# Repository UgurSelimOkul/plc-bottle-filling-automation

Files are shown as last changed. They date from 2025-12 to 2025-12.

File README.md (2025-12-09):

# 🏭 Industrial Bottle Filling & Packaging Automation

**An end-to-end industrial automation project designed for a 6-bottle filling, capping, and packaging line.**

This project encompasses the complete engineering lifecycle: from mechanical 3D design and cost analysis to system architecture using **Siemens S7-1200 PLC** and **TIA Portal**.

---

## 📖 Table of Contents
1. [Project Overview](#-project-overview)
2. [System Architecture](#-system-architecture)
3. [Hardware & Components](#-hardware--components)
4. [Process Flow](#-process-flow)
5. [3D Design & Mechanical Layout](#-3d-design--mechanical-layout)
6. [Technical Documentation](#-technical-documentation)
7. [Budget Analysis](#-budget-analysis)

---

## 🎯 Project Overview

The goal of this project is to automate the liquid filling and packaging process to increase efficiency, hygiene, and traceability in industrial sectors such as food, beverage, and pharmaceuticals.

**Key Features:**
* **Dual Conveyor System:** Continuous flow management.
* **Station-Based Processing:** Filling, Capping, and Wrapping stations.
* **Smart Sensing:** IR/Optical sensors for precise positioning and counting.
* **Human-Machine Collaboration:** Semi-automatic design allowing operator intervention for quality control.

---

## ⚙️ System Architecture

The system operates on a cyclic logic controlled by a **Siemens S7-1214C PLC**.

1.  **Input Stage:** Empty bottles are fed into Conveyor 1 and counted (Batch size: 6).
2.  **Filling Station:** Bottles are clamped, and the filling robot dispenses liquid (Time-controlled).
3.  **Capping Station:** Caps are placed and tightened using a rotary actuator.
4.  **Transfer:** Operators inspect and move bottles to Conveyor 2.
5.  **Wrapping Station:** Bottles are detected, wrapped with stretch film, and counted as a finished package.

---

## 🛠 Hardware & Components

| Component | Quantity | Function |
| :--- | :--- | :--- |
| **PLC** | 1 | Siemens S7-1214C DC/DC/DC |
| **Expansion Module** | 2 | SM1222 – 16 DO Module |
| **HMI** | 1 | Siemens HMI Panel |
| **Servo Motors** | 18 | Siemens V90 (Conveyors & Robotic Arms) |
| **Sensors** | 4 | Sick GRL18S (Reflective Optical Sensor) |
| **Contactors** | 18 | Siemens 3TF40-10 |

---

## 🔄 Process Flow

The automation logic is time-window based, ensuring synchronized operations without complex interlocks.

* **T = 0-2s:** Gripper arms lock the bottles.
* **T = 2-4s:** Robot arm descends.
* **T = 4-8s:** Process execution (Filling / Capping / Wrapping).
* **T = 8-10s:** Robot arm ascends.
* **T = 10-12s:** Grippers release, conveyor moves.

---

## 🎨 3D Design & Mechanical Layout

The physical layout was modeled to ensure ergonomic operation and spatial efficiency.

### System Overview (Isometric View)
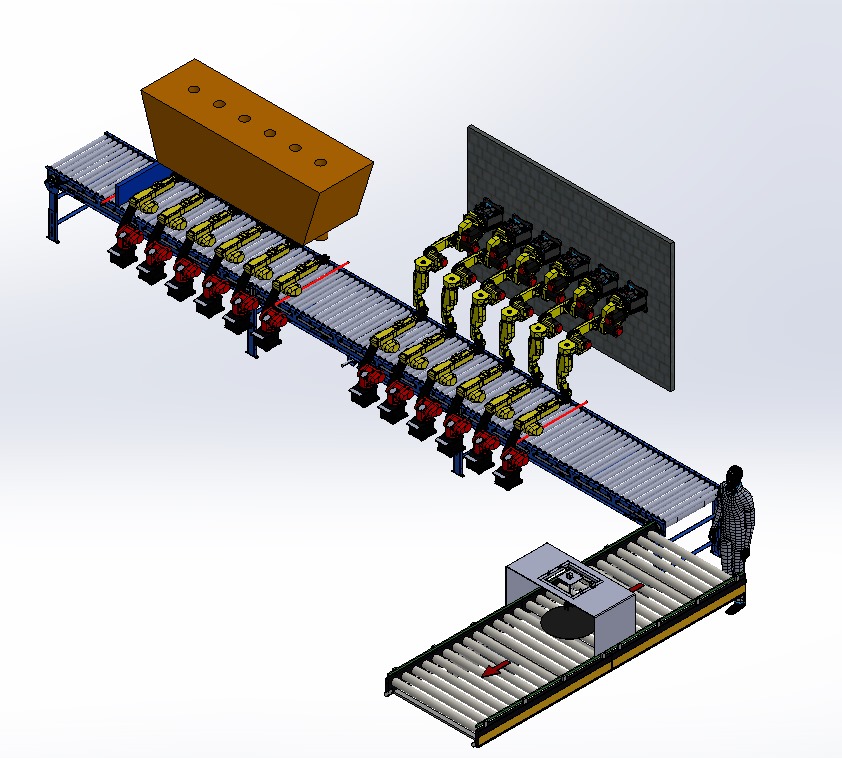
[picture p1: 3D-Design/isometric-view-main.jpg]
Isometric Main


### Front View
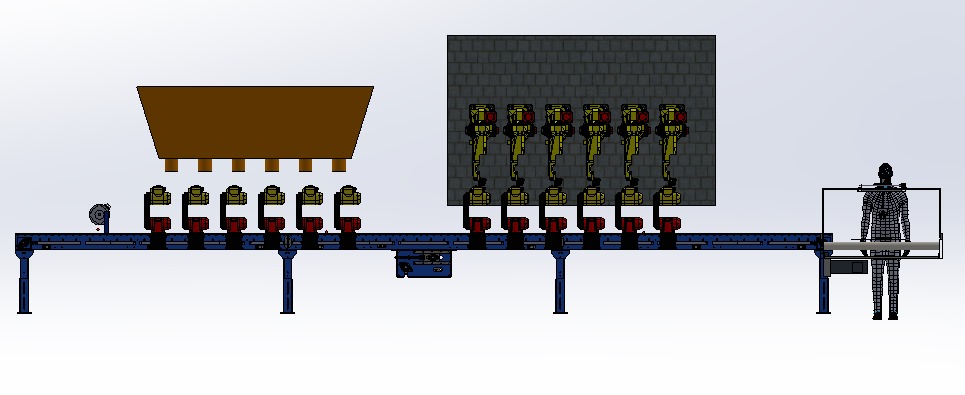
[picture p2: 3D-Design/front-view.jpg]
Front View


### Top View (Layout)
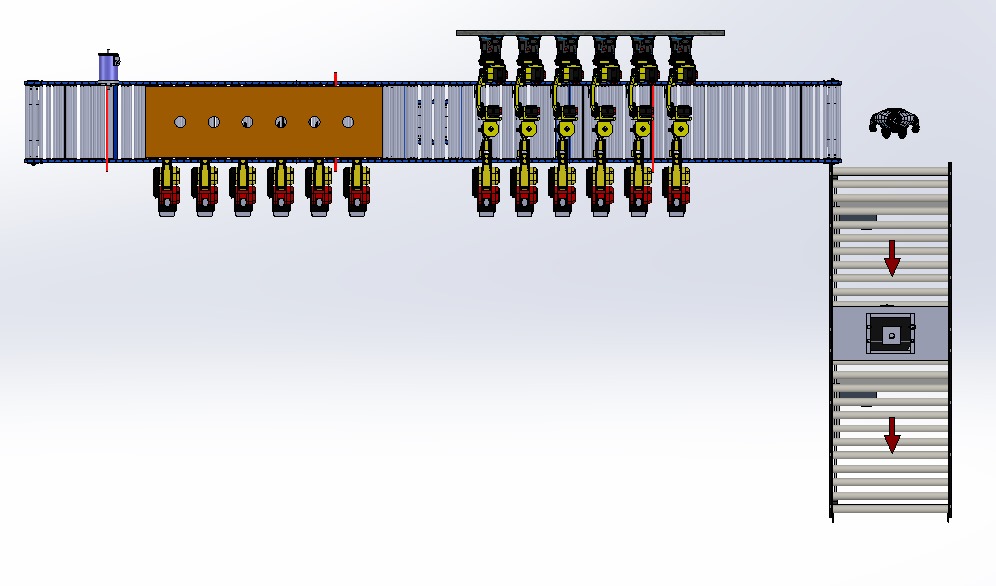
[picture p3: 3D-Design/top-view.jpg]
Top View


### Additional Angles
| Angle 1 | Angle 2 |
| :---: | :---: |
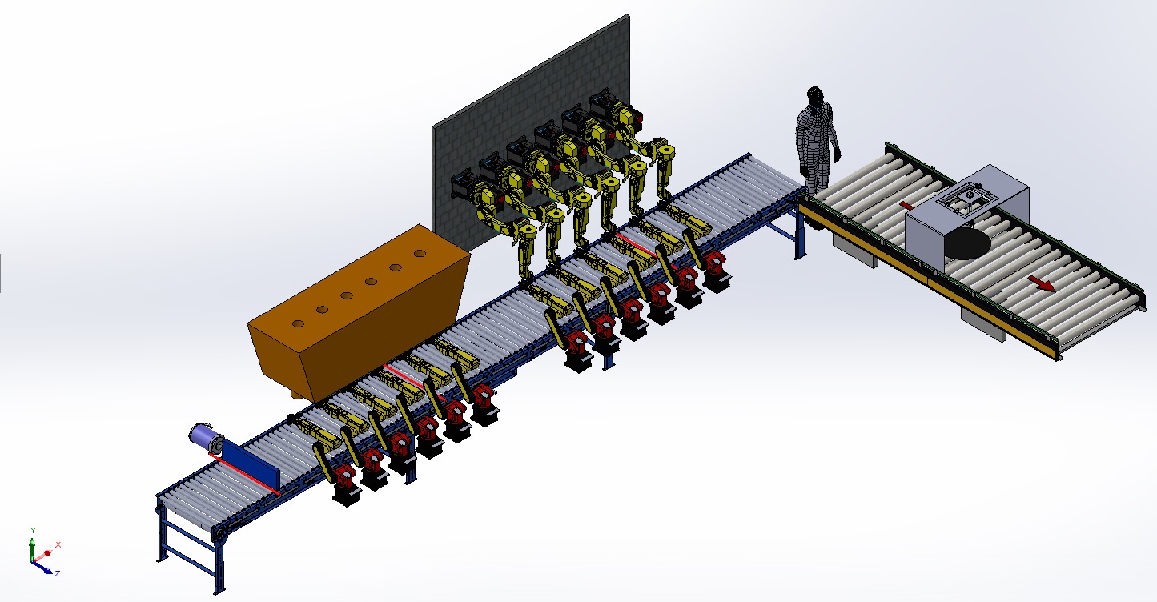
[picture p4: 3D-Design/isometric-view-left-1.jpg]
Left 1
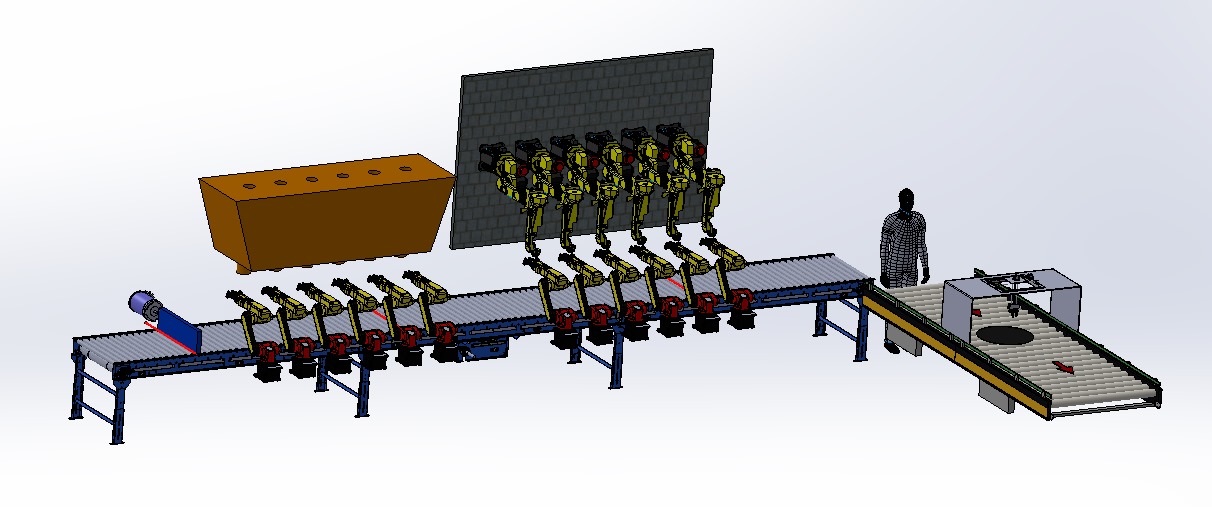
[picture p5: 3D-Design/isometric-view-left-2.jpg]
Left 2
|  |  |

---

## 📄 Technical Documentation

Detailed wiring diagrams, power circuit schematics, and PLC ladder logic diagrams are available in the full project report attached to this repository.

**The full report includes:**
* Detailed PLC Logic & Algorithms (LAD)
* Electrical Power Circuit Diagrams
* I/O Wiring Schematics

📥 **[Download Full Project Report (PDF)](Project-Report.pdf)**

---

## 💰 Budget Analysis

A comprehensive cost analysis was conducted for industrial feasibility.

| Item | Total Cost (Est.) |
| :--- | :--- |
| **PLC & Modules** | 33,600 TL |
| **HMI Panel** | 83,000 TL |
| **Servo Motors (x18)** | 248,400 TL |
| **Total System Cost** | **~415,638 TL** |

---

### 👨‍💻 Author
**Uğur Selim Okul**
*Electrical & Electronics Engineering Student*
* [GitHub Profile](https://github.com/UgurSelimOkul)

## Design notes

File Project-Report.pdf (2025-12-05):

# ENDÜSTRİYEL OTOMASYON

# 6’lı Şişe Dolum ve Paketleme

# UĞUR SELİM OKUL

## 21 MAYIS 2025

### SELÇUK ÜNİVERSİTESİ ELEKTRİK ELEKTRONİK MÜHENDİSLİĞİ

## İçindekiler

## 1. GİRİŞ

Günümüzde sanayi üretim süreçlerinin otomatikleştirilmesi, verimlilik, kalite ve hız açısından büyük önem taşımaktadır. Özellikle sıvı ürünlerin ambalajlanmasında kullanılan dolum ve paketleme otomasyon sistemleri, gıda, kimya ve ilaç sanayi gibi birçok alanda yaygın biçimde kullanılmaktadır. Bu sistemler, insan gücüne olan bağımlılığı azaltmakta; üretim hızını artırmakta ve standartlara uygun, tekrarlanabilir işlemler gerçekleştirmektedir.

Bu rapor kapsamında, iki konveyörlü, sensör kontrollü ve kısmen insan destekli bir şişe dolum ve paketleme otomasyon sistemi detaylı bir şekilde incelenmiştir. Tasarlanan sistem; şişelerin belirli sayılarda hatta alınması, dolum yapılması, kapak takılması, streçleme uygulanması ve üretim adetlerinin sayılarak gün sonunda raporlanması işlevlerini otomatik olarak yerine getirmektedir.

Çalışmada, sistemin genel yapısı, kullanılan donanım bileşenleri, işleyiş algoritması, sensör-aktüatör etkileşimi ve zamanlama mekanizmaları teknik detaylarıyla ele alınmıştır. Ayrıca sistemin gerçek dünya kullanım senaryoları ve sanayi uygulamaları da değerlendirilerek, projenin endüstriyel karşılığı vurgulanmıştır.

## 2. UYGULAMA ALANLARI VE ENDÜSTRİYEL ÖNEMİ

Şişe dolum ve paketleme sistemleri, endüstriyel otomasyonun en yaygın kullanıldığı alanlardan biridir. Yüksek hacimli, hızlı ve hijyenik üretim gereksinimi olan sektörlerde, bu tür sistemler kritik rol oynamaktadır. Otomatik dolum ve paketleme hatları aşağıdaki alanlarda yaygın biçimde kullanılmaktadır:

- Gıda Sektörü: Su, süt, meyve suyu, ayran gibi sıvı ürünlerin dolumu ve ambalajlanmasında.
- İçecek Endüstrisi: Gazlı içecekler, enerji içecekleri ve aromalı içeceklerin şişelenmesinde.
- Kimya Sanayi: Temizlik ürünleri, sıvı sabunlar, dezenfektanlar ve solvent bazlı sıvıların dolumunda.
- İlaç ve Medikal Sektör: Şurup, serum ve sıvı ilaçların dolumunda, hijyenik ve kontrollü ortam gereksinimiyle.
- Kozmetik Endüstrisi: Kolonya, parfüm, yüz tonikleri gibi sıvı kozmetik ürünlerin ambalajlanmasında.

Bu sistemlerin tercih edilmesindeki temel nedenler şunlardır:

- Üretim Hızı: İnsan gücüne göre çok daha hızlı, kesintisiz ve standardize edilmiş üretim.
- Hijyen: Özellikle gıda ve ilaç sektörlerinde, temasın minimuma indirilmesi.
- İzlenebilirlik: Sayıcı sistemler ve sensörler ile üretimin anlık takibi ve raporlanması.
- İş Gücü Tasarrufu: Sürecin büyük kısmı otomatik olduğu için daha az personelle daha fazla üretim yapılabilmesi.
- Hata Oranı Azaltımı: Zamanlamaya dayalı sistemler sayesinde kapak takma, dolum seviyesi gibi adımlarda hata olasılığı düşürülür.

Sonuç olarak, geliştirilen bu sistem yalnızca teorik bir proje değil, gerçek endüstriyel ihtiyaçlara yanıt veren, ölçeklenebilir bir otomasyon çözümünün temelini oluşturmaktadır.

## 3. SİSTEMİN GENEL TANIMI

Tasarımı gerçekleştirilen şişe dolum ve paketleme otomasyon sistemi, üretim hattında sıvı ürünlerin kapalı ve taşıma hazır hâle getirilmesini sağlayan çok aşamalı bir yapıya sahiptir. Sistem, iki ana konveyör hattı ve bu hatlar üzerinde yer alan sensörler, robot kollar, aktüatörler ve zaman kontrollü motorlar ile entegre bir şekilde çalışmaktadır. Temel hedef; sürekli bir şişe akışı sağlayarak, üretimin kesintisiz ve kontrollü biçimde sürdürülmesidir.

İşleyiş mantığı şu şekilde özetlenebilir:

1. Konveyör 1 üzerinde dış ortamdan gelen boş şişeler, bir sensör yardımıyla sayılarak 6'lı gruplar hâlinde hatta alınır. Sayı 6 olduğunda sistem geçici olarak şişe girişini durdurur.
2. Şişeler sırayla dolum istasyonuna ulaşır. Bu istasyonda tutucu kollar, şişeleri sabitler; dolum robotu aşağı inerek belirlenen süre boyunca sıvı dolumunu gerçekleştirir. İşlem tamamlandığında sistem kendini sıfırlar ve şişeler ilerlemeye devam eder.
3. Bir sonraki adımda şişeler kapak takma istasyonuna ulaşır. Burada yine tutucu kollar şişeleri tutar, ardından kapak takma robotu ve döndürücü mekanizma kapakları sıkıca yerleştirir.
4. Şişeler bu işlemlerden sonra bir insan operatör tarafından konveyör 1 sonundan alınır ve düzgün biçimde Konveyör 2 üzerine yerleştirilir.
5. Konveyör 2 operatör tarafından çalıştırıldığında, şişeler streçleme istasyonuna ulaşır. Burada şişeler sensör ile algılanır ve konveyör 2 durdurulur. Streçleme motoru belirli bir süre çalışarak şişeleri sarar ve işlemi tamamlar.
6. Streçlenmiş şişeler ilerlerken çıkıştaki sayaç ve sensör sistemiyle toplam üretim miktarı kaydedilir.

Bu yapı ile sistem hem otomatik kontrol hem de yarı-insan destekli müdahale adımlarını birleştirerek, esnek ve pratik bir üretim süreci sunar. Tüm kritik hareketler; süre, sensör geri bildirimi veya kullanıcı girişi (örneğin start butonu) ile tetiklenmektedir.

Döngüsel İşleyiş:
Sistem, kapak takma işlemi tamamlandıktan sonra otomatik olarak yeni 6'lı şişe grubunu hatta almak üzere tekrar başa döner. Bu sayede üretim hattı, manuel durdurma harici sürekli akış hâlinde çalışabilir.

Genel Yapı Özellikleri:

- Çok istasyonlu otomasyon
- Sensör-tabanlı geri besleme kontrolü
- Zamanlayıcı destekli aktüatör kontrolü
- İnsan destekli geçiş ve kalite kontrol
- Üretim takibi için entegre sayaç sistemi

## 4. DONANIM BİLEŞENLERİ VE GÖREVLERİ

Tasarlanan sistemde, şişelerin işlenmesi sırasında farklı aşamalarda çeşitli sensörler, motorlar, tutucu kollar ve kontrol elemanları görev yapmaktadır. Bu bileşenler, süreç boyunca ürün akışını yönlendirmek, işlem yapmak ve süreci kontrol etmek amacıyla kullanılır. Aşağıda sistemde yer alan donanım bileşenleri ve işlevleri detaylı olarak açıklanmıştır:

Sensörler

Sensör Adı | Türü | Konumu | Görevi
Sensör 1 | IR/optik | Konveyör 1 girişinde bulunur. | Şişe hattına giren her şişeyi algılar, giriş sayacını bir artırır. Sayaç 6’ya ulaştığında giriş motorunun durmasını sağlar.
Sensör 2 | IR/optik | Dolum istasyonunda bulunur. | Şişelerin dolum pozisyonuna geldiğini algılar; Tutucu Kol 1-6’nın ileri hareketini ve dolum robotunun aşağı inmesini tetikler.
Sensör 3 | IR/optik | Kapak takma bölgesinde bulunur. | Şişelerin kapak yerleştirme pozisyonuna ulaştığını algılar; Tutucu Kol 7-12’nin ileri hareketini ve kapak robotunun çalışmasını başlatır.
Sensör 4 | IR/optik | Streçleme bölgesinde bulunur. | Şişelerin streçleme pozisyonuna ulaştığını algılar; konveyör 2’yi durdurur ve streçleme motorunun çalışmasını başlatır. Streçleme işlemi tamamlandığında, bir paket tamamlandığı için paket sayacını bir artırır.

Sayıcılar

Sayıcı | Bağlı Olduğu Sensör | Görevi
Şişe Giriş Sayacı | Sensör 1 | Konveyöre giren her şişeyi sayar. 6’ya ulaştığında şişe alma işlemini durdurur.
Paket Sayacı | Sensör 4 | Streçleme işlemi tamamlandığında bir paketi sayar ve üretim adedini artırır.

Motorlar ve Aktüatörler

Bileşen | Görevi | Hareket Yönü | Tetikleyici
Giriş Motoru | Konveyör 1’e şişe alır | Tek yönlü (ileri) | Ana Start aktifken çalışır. Sensör 1 sayacı 6’ya ulaştığında durur.
Konveyör 1 Motoru | Şişeleri istasyonlara taşır | Tek yönlü (ileri) | Ana Start ile sürekli çalışır.
Tutucu Kol 1 Tutucu Kol 2 Tutucu Kol 3 Tutucu Kol 4 Tutucu Kol 5 Tutucu Kol 6 | Dolum istasyonunda şişeleri sabitler | İleri / Geri | Sensör 2 ile ileri hareket eder, dolum sonrası geri döner

Dolum Robotu | Dolum iğnesini şişe içine indirip çıkarır | Aşağı / Yukarı | Tutucu Kol 1 ileri pozisyondaysa → robot aşağı iner, vana açma için konum alır.
Dolum Vanası | Sıvı akışını kontrol eder | Aç / Kapa (solenoid) | Dolum robotu aşağıdayken → zamanlayıcı ile belirli süre açılır, sonra kapanır.
Tutucu Kol 7 Tutucu Kol 8 Tutucu Kol 9 Tutucu Kol 10 Tutucu Kol 11 Tutucu Kol 12 | Kapak takma istasyonunda şişeleri sabitler | İleri / Geri | Sensör 3 ile ileri gider, kapaklama sonrası geri döner.
Kapak Robotu | Kapağı şişeye indirir ve yerleştirir | Aşağı / Yukarı | Sensör 3 ile tetiklenir → aşağı iner, ardından döndürücü başlar. Döndürme bitince yukarı çıkar.
Döndürücü Motor | Kapağı döndürerek sıkar | Dönme hareketi | Kapak robotu aşağıdayken çalışır, zamanlayıcı ile belirli süre döner.
İnsan Operatör | Şişeleri Konveyör 2’ye dizmekle görevlidir | Manuel işlem | Kapaklanmış şişeleri düzenli biçimde Konveyör 2’ye yerleştirir
Konveyör 2 Motoru | Şişeleri streçleme istasyonuna taşır | Tek yön (ileri) | Sadece Konveyör 2 Start butonuna basıldığında çalışır.
Streçleme Robotu | Streçleme motorunu şişe hizasına indirip kalır. | Aşağı / Yukarı | Sensör 4 sonrası → önce aşağı iner, döndürme sonrası yukarı kalkar.
Streçleme Motoru | Streç filmle sarma işlemini yapar | Dönme hareketi | Streçleme robotu aşağıdayken çalışır, zamanlayıcı ile belirli süre döner.

Zamanlayıcılar
Tasarlanan otomasyon sisteminde, işlemlerin zaman kontrollü olarak senkronize biçimde yürütülmesi amacıyla her istasyon için tek zamanlayıcıya dayalı zaman pencereli kontrol yöntemi uygulanmıştır Sistemde, her istasyon için toplam işlem süresi sabitlenmiştir. Bu toplam süre, alt adımlara bölünerek her bir hareket veya işlem, belirlenen zaman aralıklarında başlatılır ve sonlandırılır. Böylece, her bir istasyon yalnızca bir zamanlayıcıya ihtiyaç duyarak, minimum kaynak kullanımıyla kesintisiz bir çalışma gerçekleştirebilmektedir.

İstasyon | Kontrol Edilen İşlemler | Zaman Aralıkları | Açıklama / İşlev
Dolum İstasyonu | Tutucu kol ileri Dolum robotu aşağı Vana açma Dolum robotu yukarı Tutucu kol geri | 0–2 sn 2–4 sn 4–8 sn 8–10 sn 10–12 sn | Şişe sabitlenir, dolum robotu aşağı iner, vana açılır ve 4 saniye dolum yapılır. Ardından robot yukarı çıkar ve tutucu kol geri döner.
Kapak Takma İstasyonu | Tutucu kol ileri Kapak robotu aşağı Döndürme aktif Kapak robotu yukarı Tutucu kol geri | 0–2 sn 2–4 sn 4–8 sn 8–10 sn 10–12 sn | Şişe tutulur, kapak robotu kapağı indirir, döndürme işlemi yapılır, robot yukarı kalkar ve kol geri çekilir.
Streçleme İstasyonu | Robot aşağı Motor dön Robot yukarı | 0–2 sn 2–6 sn 6–8 sn | Konveyör 2 durur, robot aşağı iner, streçleme motoru belirli süre döner, robot yukarı kalkar ve konveyör 2 tekrar çalışır.

Giriş / Çıkış Portları (I/O Analizi)
Otomasyon sisteminde kullanılan tüm sensörler, butonlar ve aktüatörler; dijital giriş ve çıkış pinleri üzerinden kontrol edilmekte ve denetlenmektedir. Endüstride yaygın olarak kullanılan PLC sistemleri referans alınarak, girişler Ix.y ve çıkışlar Qx.y formatında adreslenmiştir. Bu yapı, sistemin sahada uygulanabilirliğini kolaylaştırmakta, modülerliği ve okunabilirliği artırmaktadır.
Adresler atanırken, benzer işleve sahip bileşenler ardışık olarak gruplanmış ve sistemin genel akışına uygun şekilde sıralanmıştır. Böylece kontrol mantığı sahada daha kolay entegre edilebilir hale getirilmiştir.

Dijital Giriş Elemanları

Adres | Eleman Adı | Görevi
I0.0 | Sensör 1 | Konveyör 1 girişinde şişe algılar; giriş sayacını artırır.
I0.1 | Sensör 2 | Dolum pozisyonuna gelen şişeyi algılar; dolum sürecini başlatır.
I0.2 | Sensör 3 | Kapak takma pozisyonundaki şişeyi algılar; kapaklama işlemini tetikler.
I0.3 | Sensör 4 | Streçleme pozisyonuna gelen şişeyi algılar; işlem ve sayımı başlatır.
I0.4 | Ana Start Butonu | Tüm sistemi başlatır.
I0.5 | Ana Stop Butonu | Sistemi durdurur.
I0.6 | Konveyör 2 Start Butonu | Konveyör 2'yi manuel olarak başlatır.
I0.7 | Acil Durdurma Butonu | Sistemdeki tüm enerjiyi keser.
TOPLAM GİRİŞ SAYISI | | 8

Dijital Çıkış Elemanları

Adres | Eleman Adı | Görevi
Q0.0 | Giriş Motoru | Konveyör 1’e şişe alır.
Q0.1 | Konveyör 1 Motoru | Şişeleri dolum ve kapak istasyonlarına taşır.
Q0.2 | Tutucu Kol 1 – İleri | Dolum istasyonunda şişeyi sabitler.

Q0.3 | Tutucu Kol 1 – Geri | Sabitlenen şişeyi serbest bırakır.
Q0.4 | Tutucu Kol 2 – İleri | Dolum istasyonunda şişeyi sabitler.
Q0.5 | Tutucu Kol 2 – Geri | Sabitlenen şişeyi serbest bırakır.
Q0.6 | Tutucu Kol 3 – İleri | Dolum istasyonunda şişeyi sabitler.
Q0.7 | Tutucu Kol 3 – Geri | Sabitlenen şişeyi serbest bırakır.
Q1.0 | Tutucu Kol 4 – İleri | Dolum istasyonunda şişeyi sabitler.
Q1.1 | Tutucu Kol 4 – Geri | Sabitlenen şişeyi serbest bırakır.
Q8.0 | Tutucu Kol 5 – İleri | Dolum istasyonunda şişeyi sabitler.
Q8.1 | Tutucu Kol 5 – Geri | Sabitlenen şişeyi serbest bırakır.
Q8.2 | Tutucu Kol 6 – İleri | Dolum istasyonunda şişeyi sabitler.
Q8.3 | Tutucu Kol 6 – Geri | Sabitlenen şişeyi serbest bırakır.
Q8.4 | Dolum Robotu – Aşağı | Dolum kolu inişi
Q8.5 | Dolum Robotu – Yukarı | Dolum kolu inişi
Q8.6 | Dolum Vanası | Sıvı akışını başlatır/durdur
Q8.7 | Tutucu Kol 7 – İleri | Kapak Takma istasyonunda şişeyi sabitler.
Q9.0 | Tutucu Kol 7 – Geri | Kapak Takma istasyonunda şişeyi serbest bırakır.
Q9.1 | Tutucu Kol 8 – İleri | Kapak Takma istasyonunda şişeyi sabitler.
Q9.2 | Tutucu Kol 8 – Geri | Kapak Takma istasyonunda şişeyi serbest bırakır.
Q9.3 | Tutucu Kol 9 – İleri | Kapak Takma istasyonunda şişeyi sabitler.
Q9.4 | Tutucu Kol 9 – Geri | Kapak Takma istasyonunda şişeyi serbest bırakır.
Q9.5 | Tutucu Kol 10 – İleri | Kapak Takma istasyonunda şişeyi sabitler.
Q9.6 | Tutucu Kol 10 – Geri | Kapak Takma istasyonunda şişeyi serbest bırakır.
Q9.7 | Tutucu Kol 11 – İleri | Kapak Takma istasyonunda şişeyi sabitler.
Q12.0 | Tutucu Kol 11 – Geri | Kapak Takma istasyonunda şişeyi serbest bırakır.
Q12.1 | Tutucu Kol 12 – İleri | Kapak Takma istasyonunda şişeyi sabitler.
Q12.2 | Tutucu Kol 12 – Geri | Kapak Takma istasyonunda şişeyi serbest bırakır.
Q12.3 | Kapak Robotu – Aşağı | Kapak indirme
Q12.4 | Kapak Robotu – Yukarı | Kapak kaldırma
Q12.5 | Döndürücü Motor | Kapak döndürme
Q12.6 | Konveyör 2 Motoru | Streçleme öncesi taşıma
Q12.7 | Streçleme Robotu – Aşağı | Streç nozulu aşağı iner.
Q13.0 | Streçleme Robotu – Yukarı | Sarma işlemi tamamlandıktan sonra yukarı çıkar.
Q13.1 | Streçleme Motoru | Streç film sarımını gerçekleştirir.
TOPLAM ÇIKIŞ SAYISI: | | 36

## 5. SİSTEM İŞLEYİŞ AKIŞI

Genel Çalışma Mantığı

Tasarlanan şişe dolum ve ambalajlama otomasyon sistemi, konveyör hatları üzerinde sensörlerden alınan geri bildirimlerle çalışan motor, aktüatör ve zaman kontrollü işlemlerden oluşmaktadır. Sistemin kontrolü, Ana Start butonuna basılması ile başlar ve tüm işlemler sıralı biçimde gerçekleşir. Her istasyon belirli bir işlem süresine sahiptir ve bu süre içerisinde alt adımlar belirlenen zaman aralıklarında gerçekleştirilir.

Sistem ayrıca yarı otomatik bir yapıya sahiptir. Şişelerin Konveyör 2 üzerine dizilmesi, insan operatör tarafından gerçekleştirilmektedir.

İşleyiş Adımları

1. Ana Start butonuna basılır ve sistem devreye girer.
2. Giriş motoru (Q0.0) çalışarak Konveyör 1 üzerine şişe almaya başlar.
3. Sensör 1 (I0.0) şişeleri algılayarak giriş sayacını artırır. Sayaç değeri 6 olduğunda, giriş motoru durur.
4. Konveyör 1 motoru (Q0.1) aktif hale gelir ve şişeleri dolum istasyonuna taşır.
5. Sensör 2 (I0.1) dolum pozisyonuna gelen şişeyi algılar ve dolum istasyonu zamanlayıcısı başlar:
- 0–2 sn: Tutucu Kol 1-6 (Q0.2, Q0.4, Q0.6, Q1.0, Q8.0, Q8.2) ileri hareket eder.
- 2–4 sn: Dolum Robotu (Q8.4) aşağı iner.
- 4–8 sn: Dolum Vanası (Q8.6) açılır ve sıvı dolumu yapılır.
- 8–10 sn: Dolum Robotu (Q8.5) yukarı çıkar.
- 10–12 sn: Tutucu Kol 1-6 (Q0.3, Q0.5, Q0.7, Q1.1, Q8.1, Q8.3) geri hareket eder.
6. Şişeler kapak istasyonuna ilerler. Sensör 3 (I0.2) bu noktada devreye girer ve kapaklama süreci başlar:
- 0–2 sn: Tutucu Kol 7-12 (Q8.7, Q9.1, Q9.3, Q9.5, Q9.7, Q12.1) ileri hareket eder.
- 2–4 sn: Kapak Robotu – Aşağı (Q12.3) çalışır.
- 4–8 sn: Döndürücü Motor (Q12.5) kapağı sıkar.
- 8–10 sn: Kapak Robotu – Yukarı (Q12.4) çalışır.
- 10–12 sn: Tutucu Kol 7–12 Geri çıkışları (Q9.0, Q9.2, Q9.4, Q9.6, Q12.0, Q12.2) aktif olur.
7. Kapaklama işlemi tamamlanan şişeler, insan operatör tarafından manuel olarak alınır ve Konveyör 2 üzerine sıralı şekilde yerleştirilir.
8. Operatör, Konveyör 2 Start butonuna (I0.6) basar. Konveyör 2 motoru (Q12.6) çalışır ve şişeleri streçleme istasyonuna taşır.
9. Sensör 4 (I0.3), streçleme pozisyonuna gelen şişeleri algıladığında zamanlayıcı başlatılır ve Konveyör 2 durur. Streçleme istasyonu işlemleri aşağıdaki sırayla gerçekleştirilir:
- 0–2 sn: Streçleme Robotu aşağı iner (Q13.1).
- 2–6 sn: Streçleme Motoru (Q13.0) dönmeye başlar ve filmi sarar.
- 6–8 sn: Streçleme Robotu yukarı çıkar (Q13.0).
10. Streçleme Robotu yukarı çıktıktan sonra Konveyör 2 devam etmeye başlar.
11. Streçleme işlemi tamamlanan her 6’lı paket için Paket Sayacı bir artırılır.

Zaman Pencereli Kontrolün Uygulanması

Sistem içerisindeki tüm istasyonlar, kendi içlerinde sabit bir toplam süreye sahip olacak şekilde yapılandırılmıştır. Her istasyonun işlemleri, bu toplam sürenin belirli aralıklarına karşılık gelen zaman pencereleri içerisinde yürütülmektedir. Bu yaklaşımda:

- İşlemler tek bir zamanlayıcı üzerinden zaman koşullarıyla tetiklenir,

- Her hareket (ileri, geri, aşağı, yukarı) veya işlem (dolum, kapap takma) kendi pencere süresine sahiptir,
- Bu yapı, düşük kaynakla yüksek kontrol hassasiyeti sağlamaktadır.

Ayrıntılı Metinsel İşleyiş

Sistemin girişine, üretimden çıkmış kapakları takılı olmayan ve içi boş şişeler gelir. Operatör, Ana Start Butonuna (I0.4) bastığı zaman Konveyör 1 motoru (Q0.1) çalışmaya başlar ve sistemin başında bulunan Giriş Motoru (Q0.0) devreye girerek sisteme şişe almaya başlar. Onun yanında bulunan Sensör 1 (I0.0), sayıcı yardımıyla 6 adet şişe geçtiğinde Giriş Motoru (Q0.0) durur ve sisteme şişe girişi sona erer.

Konveyör 1 (Q0.1) üzerinde ilerlemeye devam eden bu 6 şişe, dolum istasyonuna ulaştığında Sensör 2 (I0.1) tarafından algılanır ve Tutucu Kol 1–6 ileri çıkışları (Q0.2, Q0.4, Q0.6, Q1.0, Q8.0, Q8.2) 2 saniye boyunca aktif hale gelir. Sensör, son tutucu kola şişelerin gelmesinden yaklaşık 2 saniye öncesine konumlandırılmıştır; bu yüzden tutucular 2 saniye çalıştığında, son tutucu kol son şişeyi başarıyla sabitlemiş olur.

Bu işlemden sonra Dolum Robotu Aşağı (Q8.4) çıkışı 2 saniye süreyle aktif olur ve robot aşağı hareket eder. Ardından Dolum Vanası (Q8.6) açılır ve 4 saniye boyunca dolum işlemi gerçekleştirilir. Sürenin sonunda vana kapanır ve Dolum Robotu Yukarı (Q8.5) çıkışı 2 saniye boyunca aktif olarak robotu eski konumuna çeker. Bu işlemin ardından, Tutucu Kol 1–6 Geri çıkışları (Q0.3, Q0.5, Q0.7, Q1.1, Q8.1, Q8.3) 2 saniyelik bir süreyle çalıştırılarak sabitlenmiş şişeler serbest bırakılır.

Tüm bu işlemleri kontrol eden Timer 1, toplam 16 saniyelik bir zaman penceresiyle çalışır. İlk 12 saniyede yukarıda açıklanan dolum süreci tamamlanır. Kalan 4 saniyede ise şişelerin tamamının Sensör 2 önünden geçerek bir sonraki istasyona ulaşmaları beklenir. Süre sonunda, sensör 2'nin mühür (onay) durumu, Timer çıkışıyla sıfırlanarak bir sonraki döngüye geçiş sağlanır.,

Sensör 3 (I0.2) şişeyi algıladığında, Tutucu Kol 7–12 İleri çıkışları (Q8.7, Q9.1, Q9.3, Q9.5, Q9.7, Q12.1) 2 saniye boyunca aktif olur ve şişeleri, dolum istasyonundaki gibi sabitler. Ardından Kapak Robotu – Aşağı (Q12.3) çıkışı aktif hale gelir ve robot 2 saniye boyunca aşağı hareket eder.

Kapak robotu tamamen aşağı indikten sonra, Döndürücü Motor (Q12.5) 4 saniye çalışarak kapakları döndürerek yerine sabitler. 4 saniyenin sonunda döndürücü motor durur ve Kapak Robotu – Yukarı (Q12.4) çıkışı 2 saniye aktif hale gelerek robotun yukarı çıkmasını sağlar.

Robot yukarı çıktıktan sonra, Tutucu Kol 7–12 Geri çıkışları (Q9.0, Q9.2, Q9.4, Q9.6, Q12.0, Q12.2) 2 saniye boyunca çalışarak şişeleri serbest bırakır. Böylece kapak takma işlemi tamamlanan şişeler bir sonraki istasyona geçmek üzere hazır hâle gelir.

Bu işlemleri kontrol eden Timer 2, tutucu kolların geri çekilmesinden sonra 4 saniye daha çalışır. Bu bekleme süresi sonunda Sensör 3’ün mühür durumu sıfırlanır, böylece sistem yeni bir döngüye geçmeye hazır hâle gelir.

Kapak takma işlemi tamamlanan şişeler, konveyör 1 bandı üzerinde ilerlemeye devam eder. Bandın sonunda bulunan operatörler, şişeleri gözle kontrol ederek hatalı olanları ayırır, uygun olanları ise konveyör 2 bandı üzerine düzenli bir şekilde dizer. Dizme işlemi tamamlandıktan sonra, operatör
Konveyör 2 Start butonuna (I0.6) basar ve Konveyör 2 Motoru (Q12.6) çalışmaya başlar. Bu andan itibaren konveyör sistemi Stop butonu (I0.1) veya Acil Stop butonu (I0.7) ile manuel olarak durdurulabilir.

Konveyör 2 üzerinde ilerleyen şişeler, streçleme istasyonuna ulaştığında burada bulunan Sensör 4 (I0.3) tarafından algılanır. Sensör 4’ün algılamasıyla birlikte Konveyör 2 Motoru (Q12.6) durdurulur ve sistem bekleme moduna geçer. Bu esnada Sensör 4 çıkışı mühürlenir ve Timer 3’e bağlanır. Timer 3 toplamda 8 saniyelik süreci yönetir.

İlk 2 saniyede Streçleme Robotu Aşağı (Q12.7) çıkışı aktif hale gelir ve robot başlığı aşağı doğru iner. Ardından robot durur ve sabitlenir. Ardından streçleme Motoru (Q13.1) 4 saniye boyunca çalışarak şişelerin etrafına streç film sarma işlemini gerçekleştirir. Dördüncü saniyenin sonunda streçleme motoru durur. Son olarak Streçleme Robotu Yukarı (Q13.0) çıkışı aktif olur ve robot 2 saniye boyunca yukarı doğru hareket ederek eski konumuna döner. Bu işlemlerin tamamlanmasının ardından, mühür kaldırılır ve Konveyör 2 tekrar çalışmaya başlar. Streçlenmiş şişeler 6’lı şekilde konveyör bandının sonuna doğru ilerler.

Bu noktada çalışan operatörler, şişeleri kontrol ederek paketleme işlemini gerçekleştirir. Paketleme işlemi tamamlanan şişeler sistemin çıkışına alınır ve satışa hazır hâle gelir.

## 6. KULLANILAN DONANIMLAR VE BÜTÇE

Bu sistemde kullanılan tüm elektriksel ve mekanik donanımlar aşağıda listelenmiş olup görev tanımları belirtilmiştir. Ayrıca sistemin toplam maliyetini gösteren bütçe tablosu da bu başlık altında sunulmuştur.

Malzeme Listesi

Malzeme Adı | Adet | Görevi
Start Butonu | 2 | Sistemi başlatmak için: biri genel sistem için, biri konveyör 2 için
Stop Butonu | 1 | Sistemi manuel olarak durdurur
Acil Stop Butonu | 1 | Sistemi acil olarak durdurur.
Siemens S7-1214C DC/DC/DC | 1 | Sistemdeki giriş ve çıkışların kontrolünü sağlar
SM1222 – 16 DO Modülü | 2 | PLC çıkış kapasitesini genişletmek için
Siemens HMI Panel | 1 | kullanıcı ile otomasyon sistemi arasındaki iletişimi sağlayarak operasyonel verimlilik, esneklik ve arıza müdahale hızını artırır.
ETİEN Enerji ABS Pano | 1 | Tüm PLC, güç kaynakları, kontaktörler ve kontrol ekipmanları bu pano içerisine yerleştirilir. Toz ve sıvıya karşı korumalıdır.
SIEMENS Kontaktör 3Tf40-10 4Kw | 18 | Her bir motor çıkışının uzaktan kontrolü ve güvenli anahtarlaması için kullanılır
Siemens 5,5 - 8A Sirius Termik Röle 3RU2116-1HB0 | 18 | Her motoru aşırı akım ve kısa devreye karşı korumak için kullanılır
Siemens 1FL6042-2AF21-1AA1 V90 LI 750W Servo Motor 2,39Nm 3000rpm | 18 | Konveyör + tutucu kol sürücüleri
Sick GRL18S-P2336 M18 PNP 6M Reflektörlü Sensör | 4 | Şişe ve ürün algılama
Dündar FT 30A EMİCİ Trifaze | 1 | Pano soğutma için kullanılacaktır.

Aksiyel Sogutma Fanı 2200 m³ 1450 RPM

Tek Damarlı Montaj Kablosu 0.5mm 100 Metre Siyah | 5 | Sistemde kullanılan güç, sinyal ve haberleşme kabloları

Bütçe Tablou

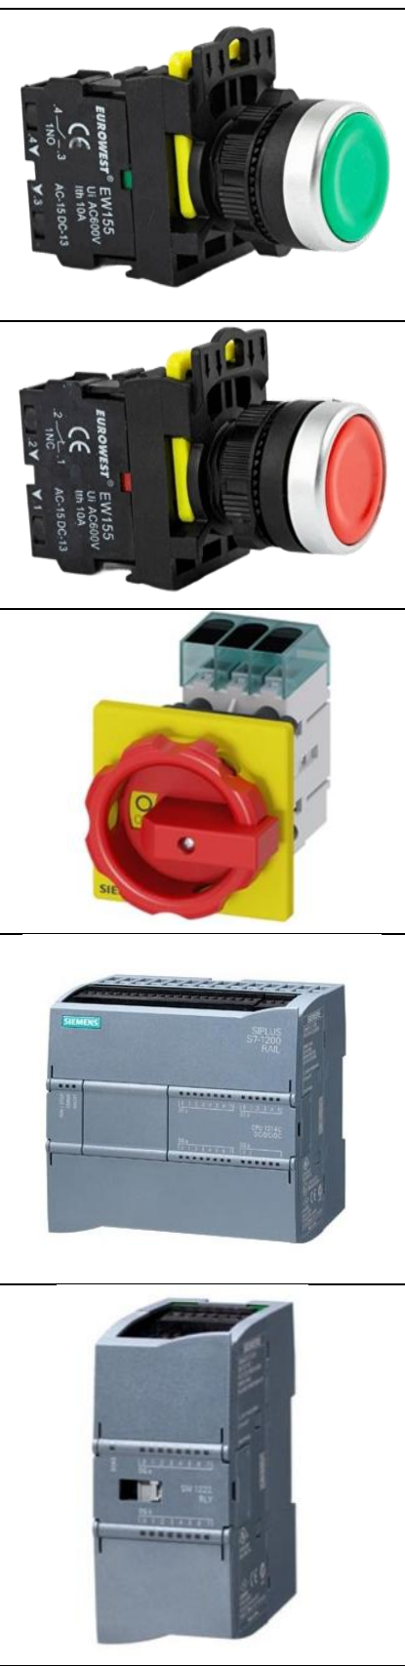
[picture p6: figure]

Malzeme Görseli | Malzeme Adı | Adet | Adet Fiyatı | Toplam Tutar
| Start Butonu | 2 | 267,75 TL | 535,50 TL
| Stop Butonu | 1 | 267,75 TL | 267,75 TL
| Acil Stop Butonu | 1 | 500 TL | 500 TL
| Siemens S7-1214C DC/DC/DC | 1 | 19.400 TL | 19.400 TL
| SM1222 – 16 DO Modülü | 2 | 7.100 TL | 14.200 TL

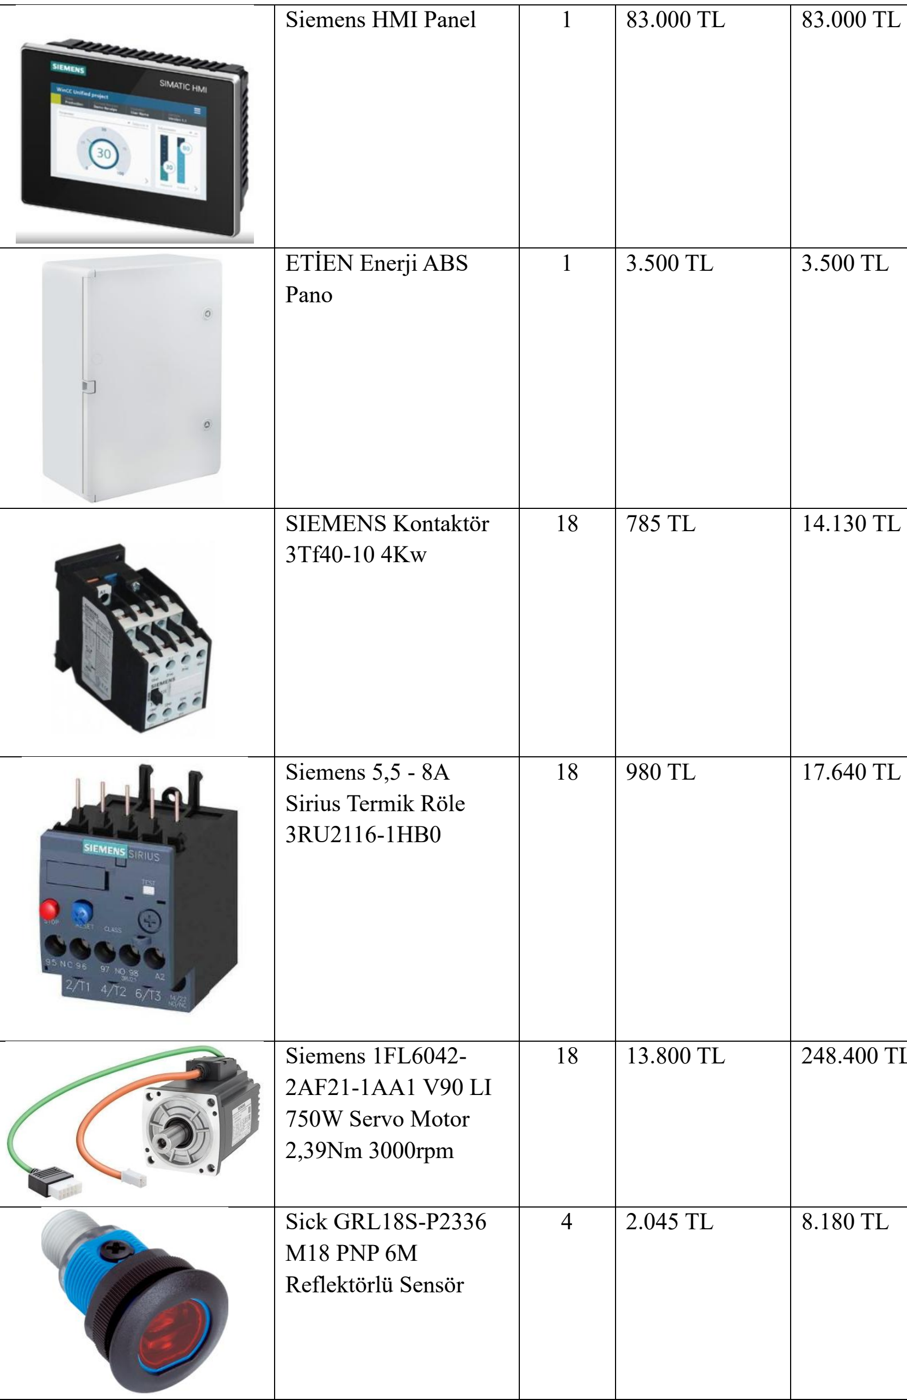
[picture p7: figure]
Siemens HMI Panel; ETİEN Enerji ABS Pano; SIEMENS Kontaktör 3Tf40-10 4Kw

Siemens 5,5 - 8A Sirius Termik Röle 3RU2116-1HB0 | 18 | 980 TL | 17.640 TL
Siemens 1FL6042-2AF21-1AA1 V90 LI 750W Servo Motor 2,39Nm 3000rpm | 18 | 13.800 TL | 248.400 TL
Sick GRL18S-P2336 M18 PNP 6M Reflektörlü Sensör | 4 | 2.045 TL | 8.180 TL

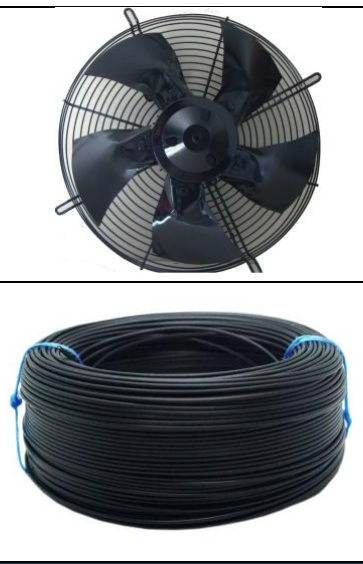
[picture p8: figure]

| Dündar FT 30A EMİCİ Trifaze Aksiyel Sogutma Fanı 2200 m³ 1450 RPM | 1 | 3.835 TL | 3.835 TL
| Tek Damarlı Montaj Kablosu 0.5mm 100 Metre Siyah | 5 | 410 TL | 2.050 TL
TOPLAM MALİYET | | | 415.638,25 TL

## 7. SİSTEMİN 3B TASARIMI

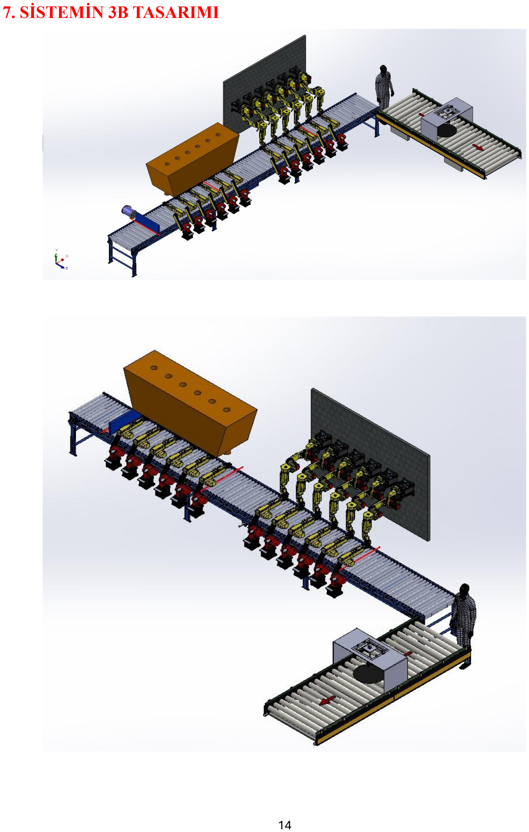
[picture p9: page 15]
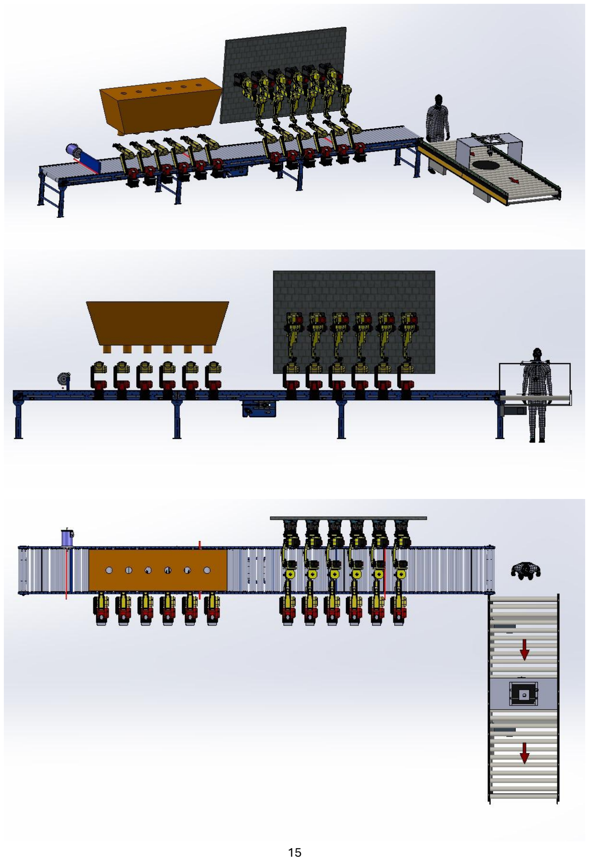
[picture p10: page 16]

## 8. PLC DIŞ DEVRE BAĞLANTI ŞEMALARI

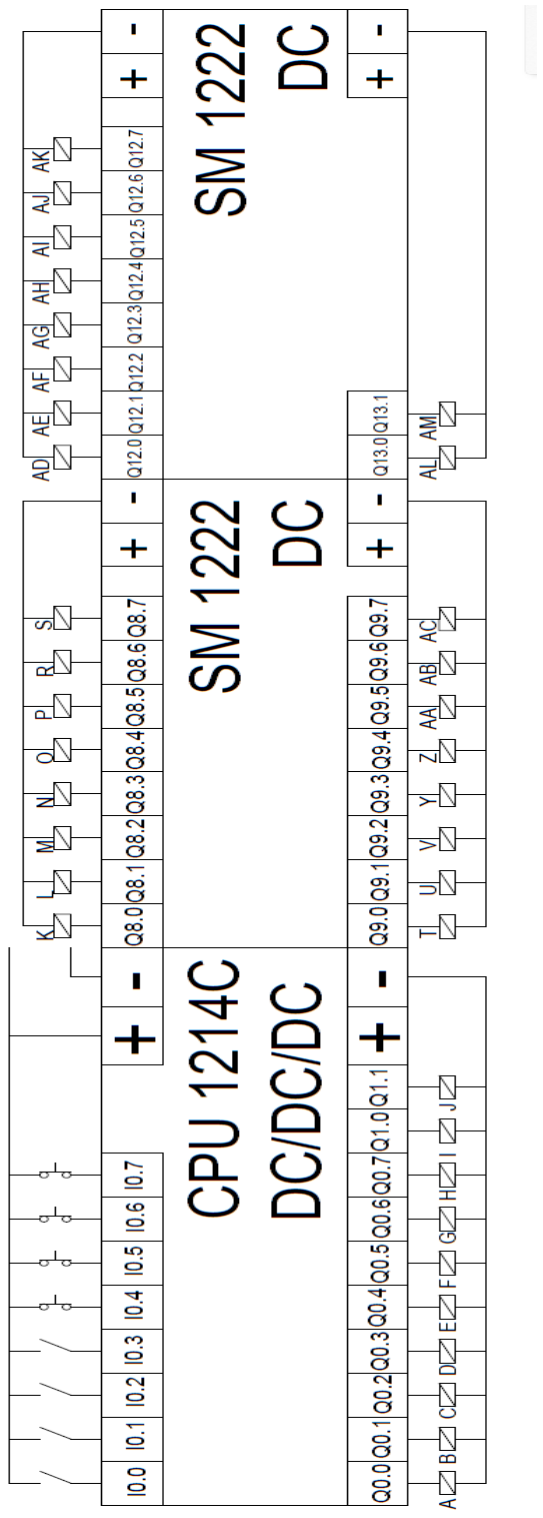
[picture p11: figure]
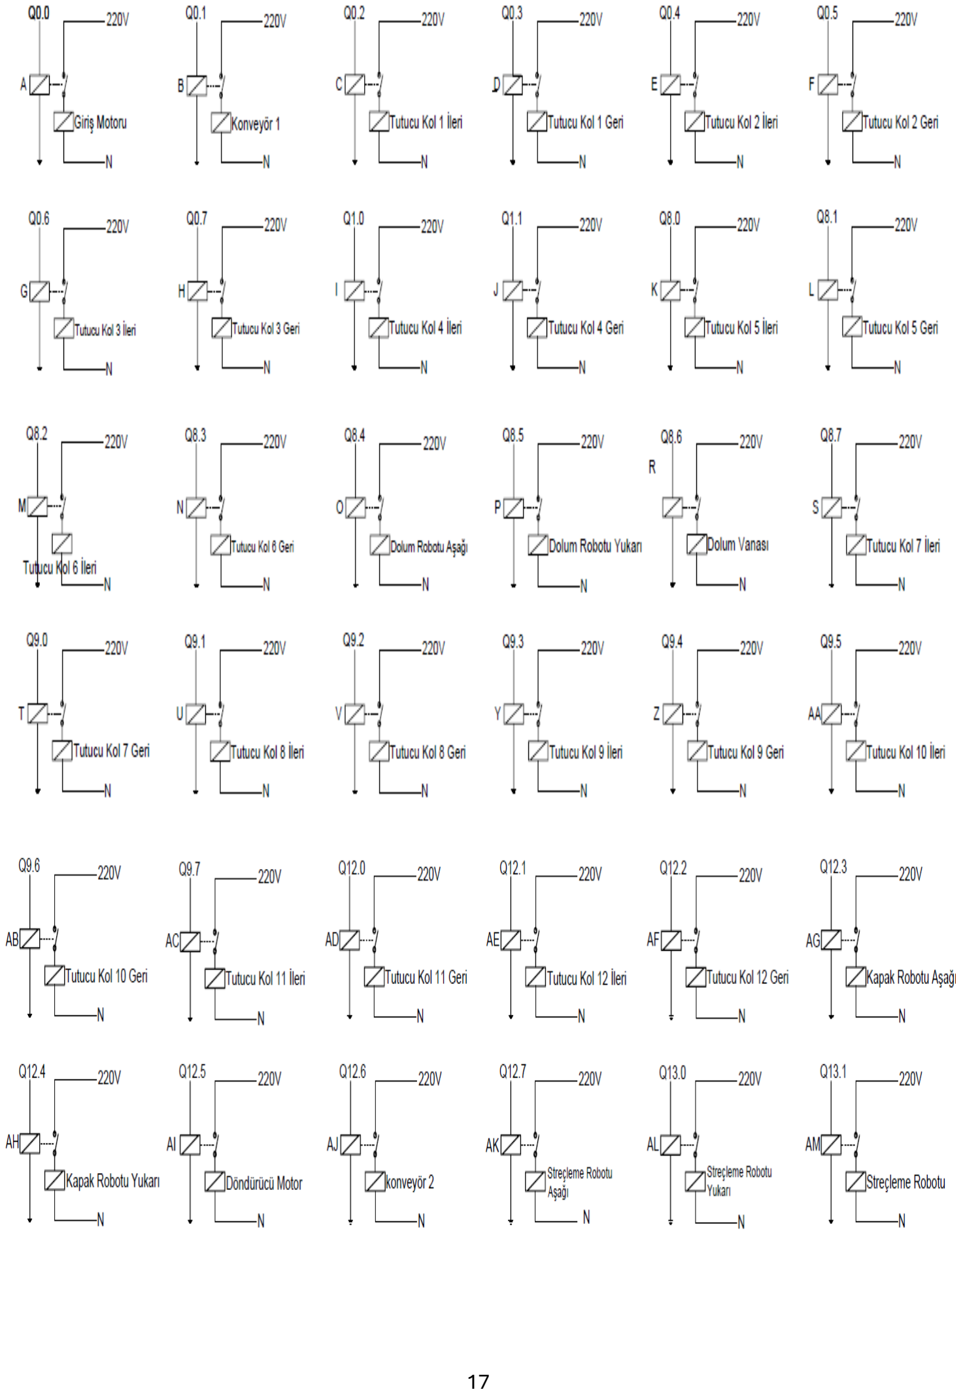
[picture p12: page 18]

## 9. GÜÇ DEVRELERİ

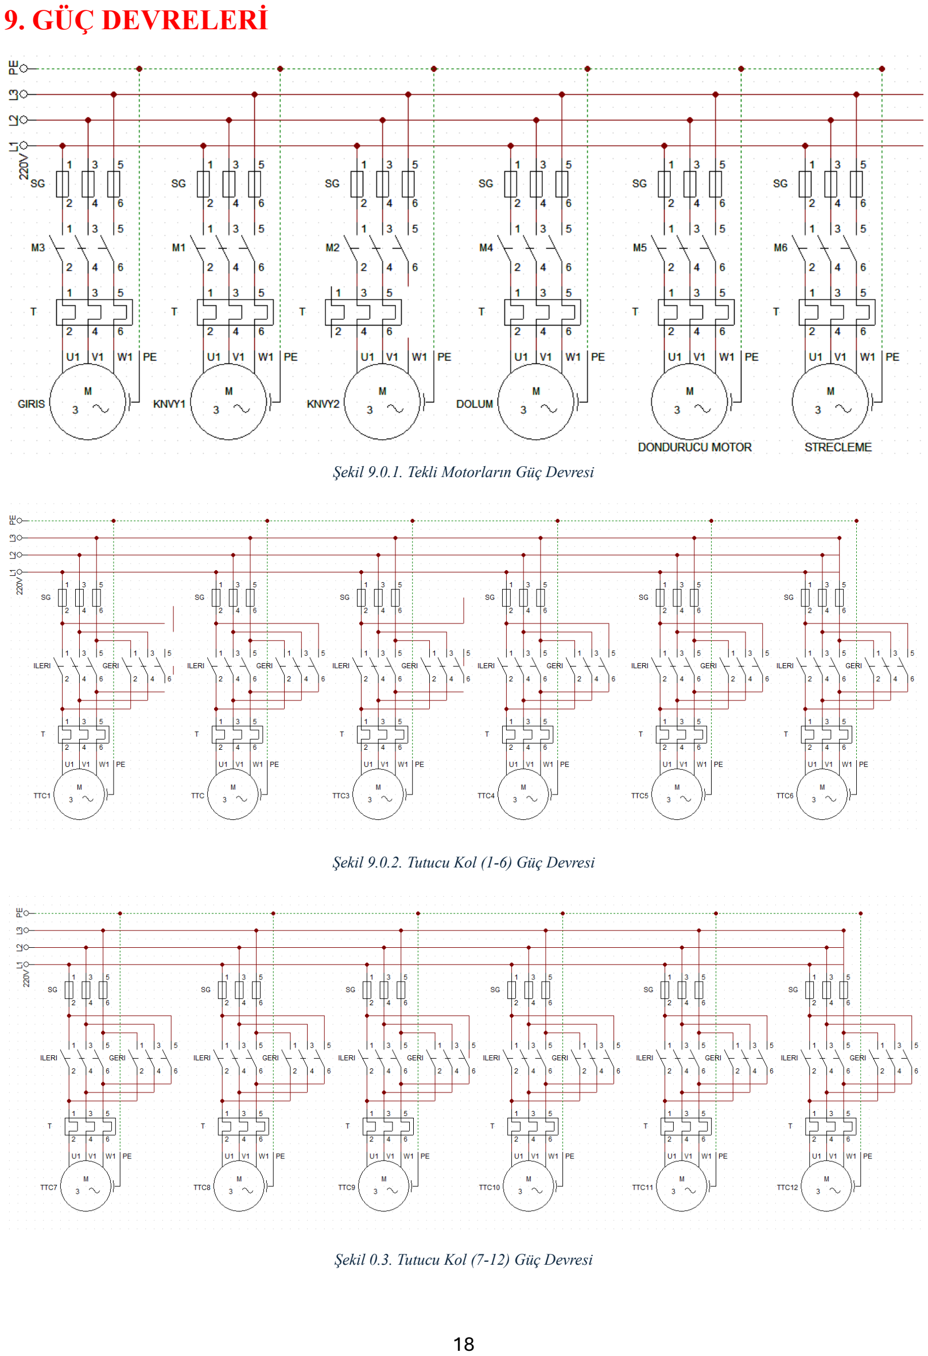
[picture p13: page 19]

Şekil 9.0.1. Tekli Motorların Güç Devresi

Şekil 9.0.2. Tutucu Kol (1-6) Güç Devresi

Şekil 0.3. Tutucu Kol (7-12) Güç Devresi

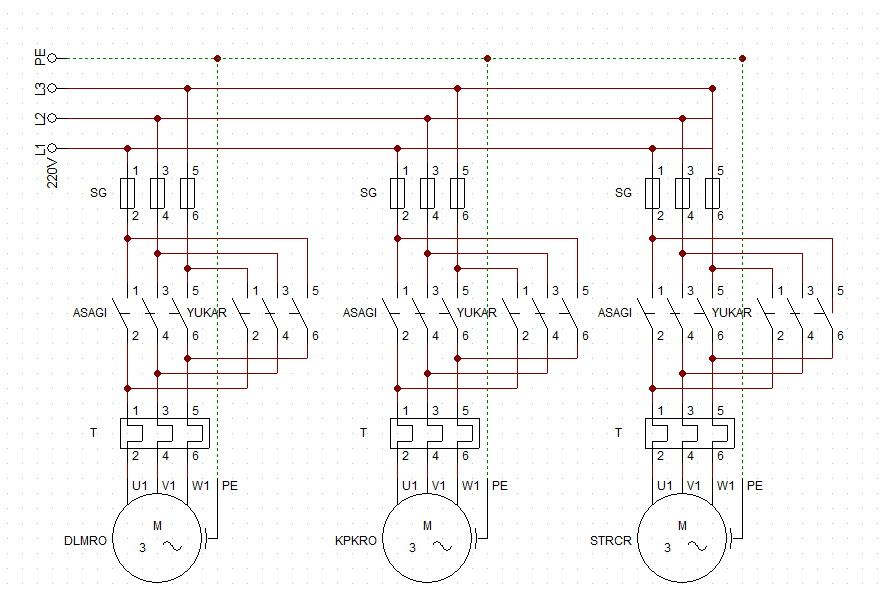
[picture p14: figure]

Şekil 0.4. Aşağı-Yukarı Robotlar Güç Devresi

## 10. TIA PORTAL ÇİZİMLERİ

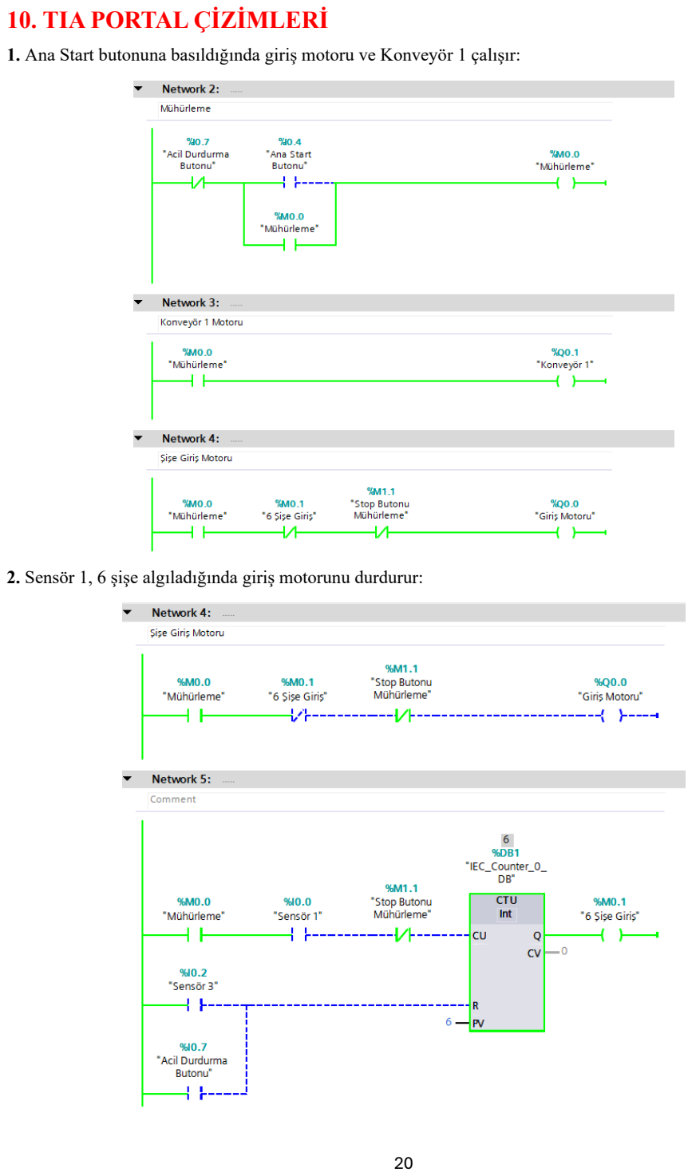
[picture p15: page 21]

### 1. Ana Start butonuna basıldığında giriş motoru ve Konveyör 1 çalışır:

### 2. Sensör 1, 6 şişe algıladığında giriş motorunu durdurur:

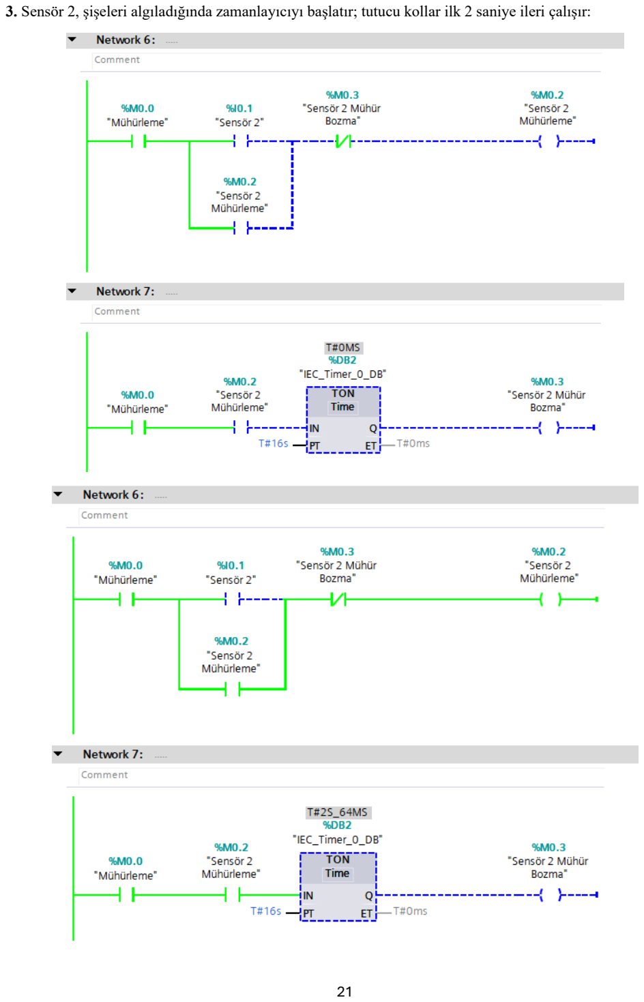
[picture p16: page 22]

3. Sensör 2, şişeleri algıladığında zamanlayıcıyı başlatır; tutucu kollar ilk 2 saniye ileri çalışır:

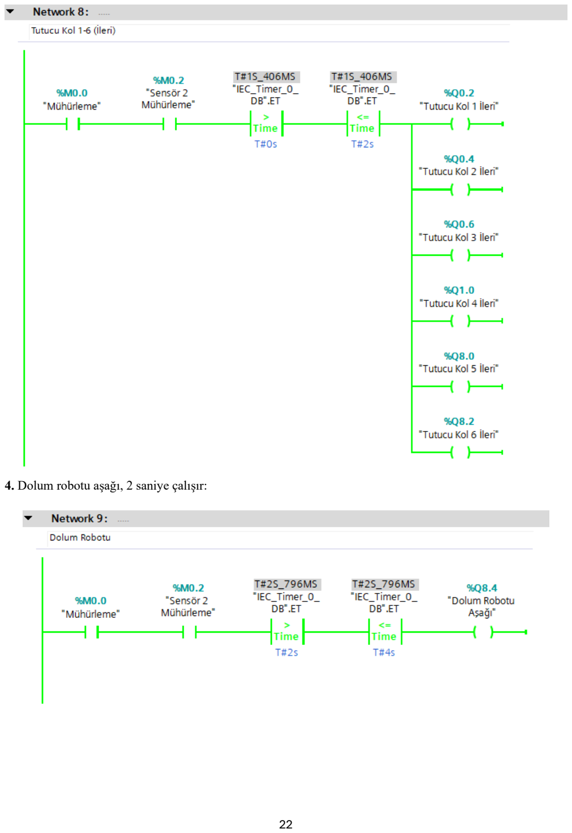
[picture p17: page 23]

### 4. Dolum robotu aşağı, 2 saniye çalışır:

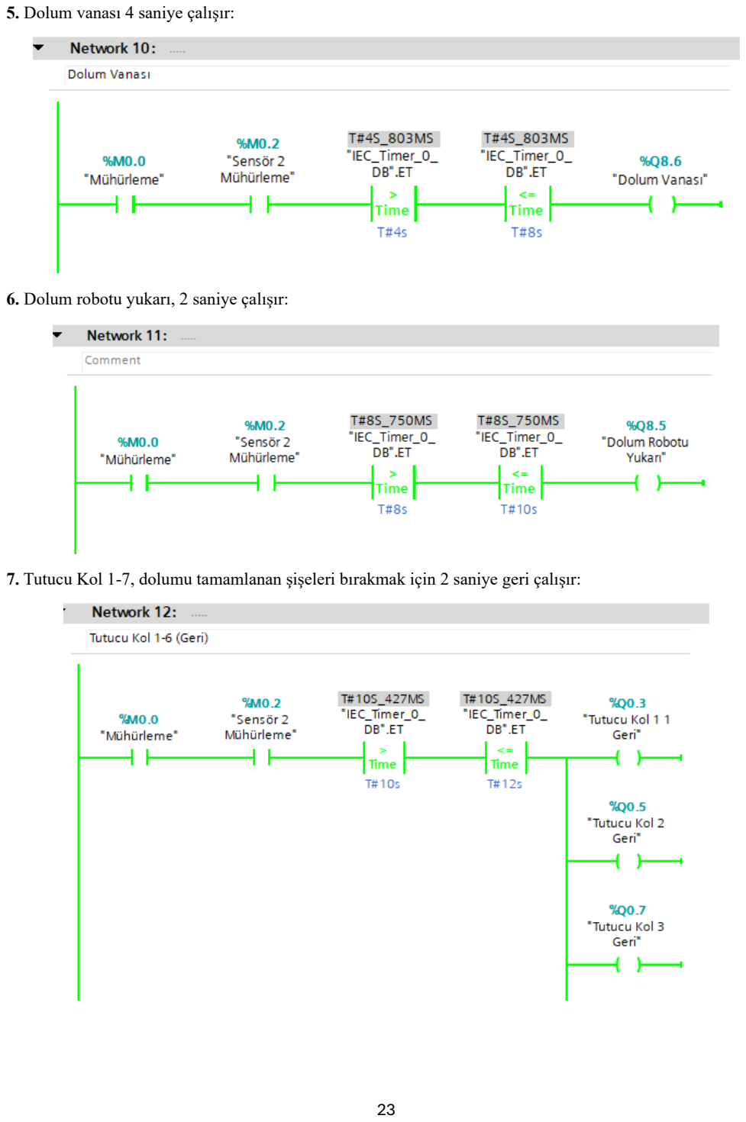
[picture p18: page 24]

### 5. Dolum vanası 4 saniye çalışır:

### 6. Dolum robotu yukarı, 2 saniye çalışır:

### 7. Tutucu Kol 1-7, dolumu tamamlanan şişeleri bırakmak için 2 saniye geri çalışır:

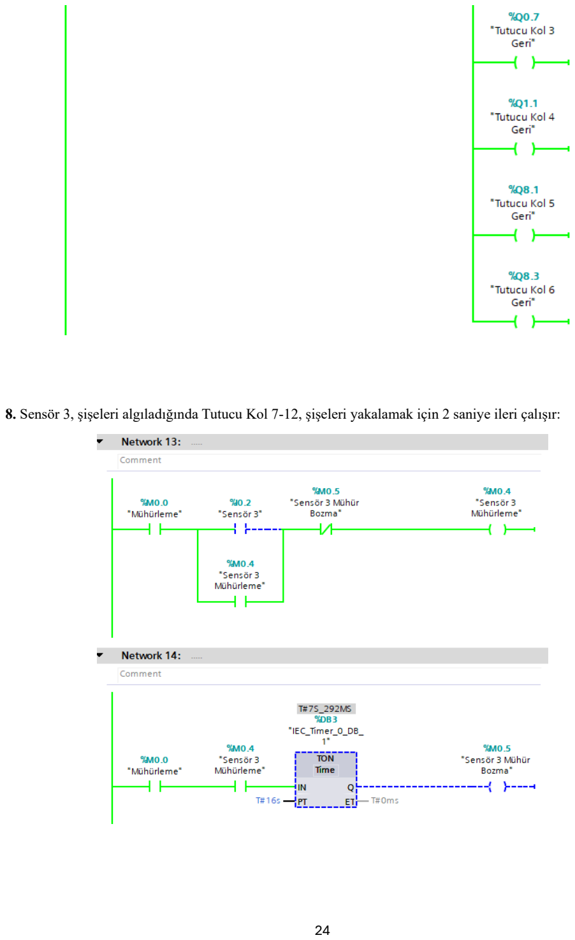
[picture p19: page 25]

8. Sensör 3, şişeleri algıladığında Tutucu Kol 7-12, şişeleri yakalamak için 2 saniye ileri çalışır:

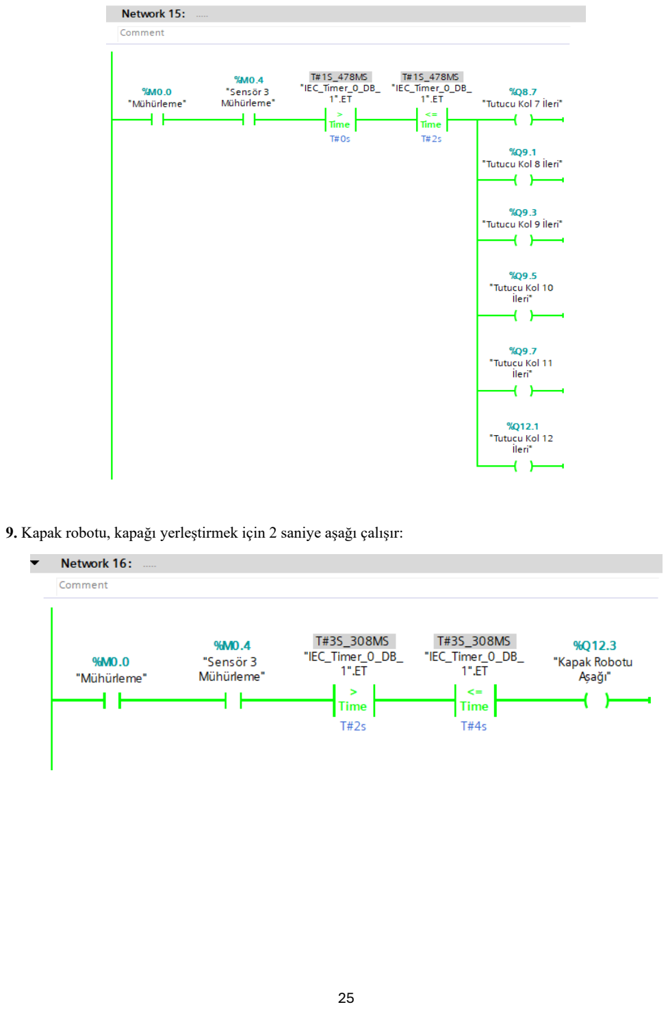
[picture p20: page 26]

### 9. Kapak robotu, kapağı yerleştirmek için 2 saniye aşağı çalışır:

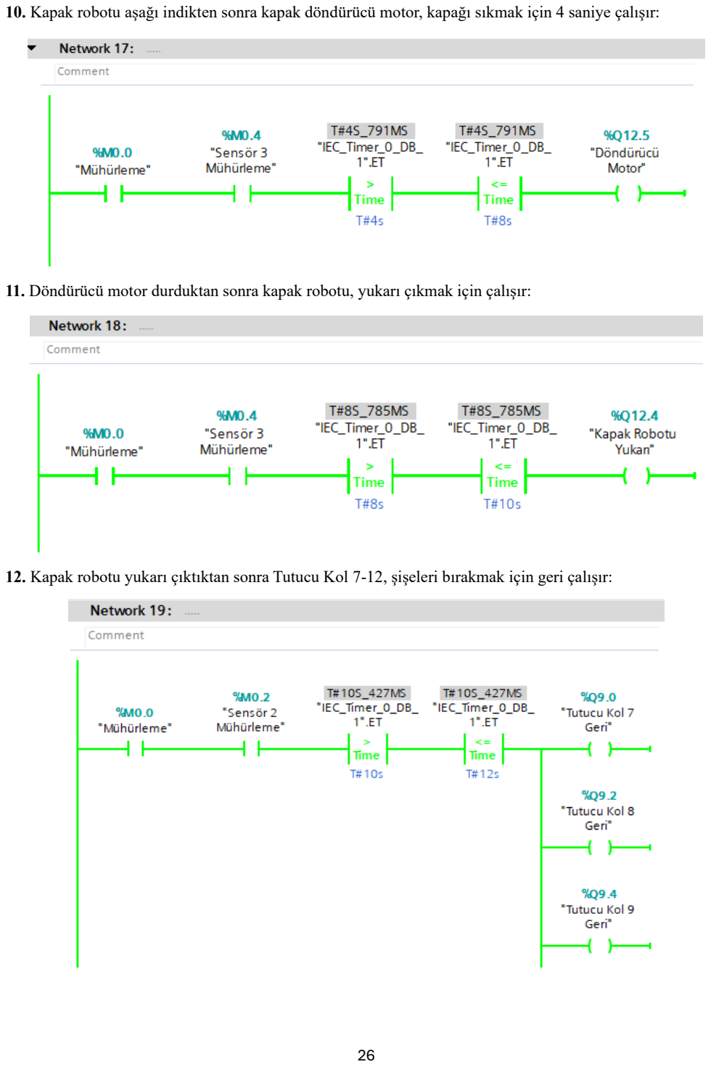
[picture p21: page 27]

10. Kapak robotu aşağı indikten sonra kapak döndürücü motor, kapağı sıkmak için 4 saniye çalışır:

### 11. Döndürücü motor durduktan sonra kapak robotu, yukarı çıkmak için çalışır:

12. Kapak robotu yukarı çıktıktan sonra Tutucu Kol 7-12, şişeleri bırakmak için geri çalışır:

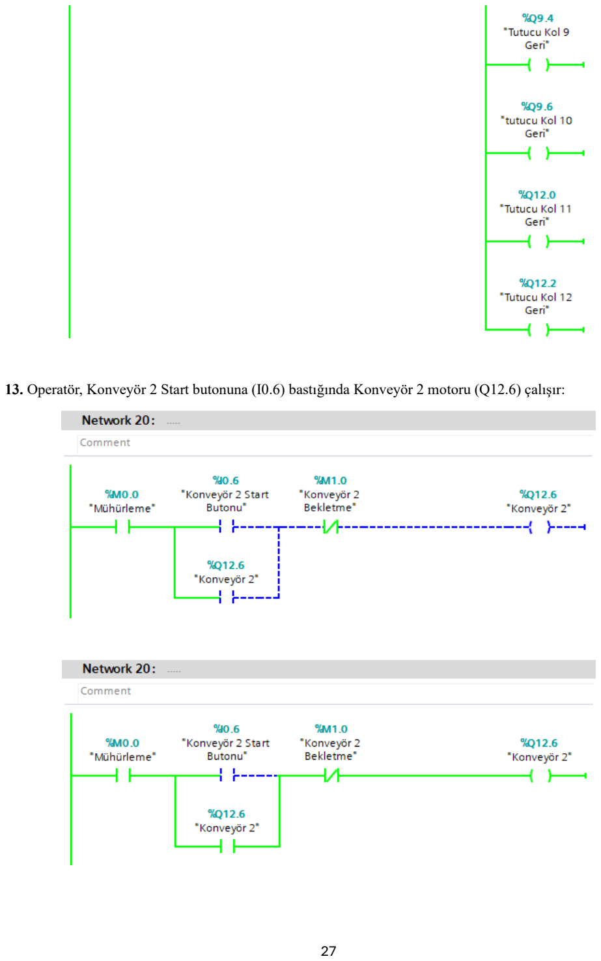
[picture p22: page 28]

13. Operatör, Konveyör 2 Start butonuna (I0.6) bastığında Konveyör 2 motoru (Q12.6) çalışır:

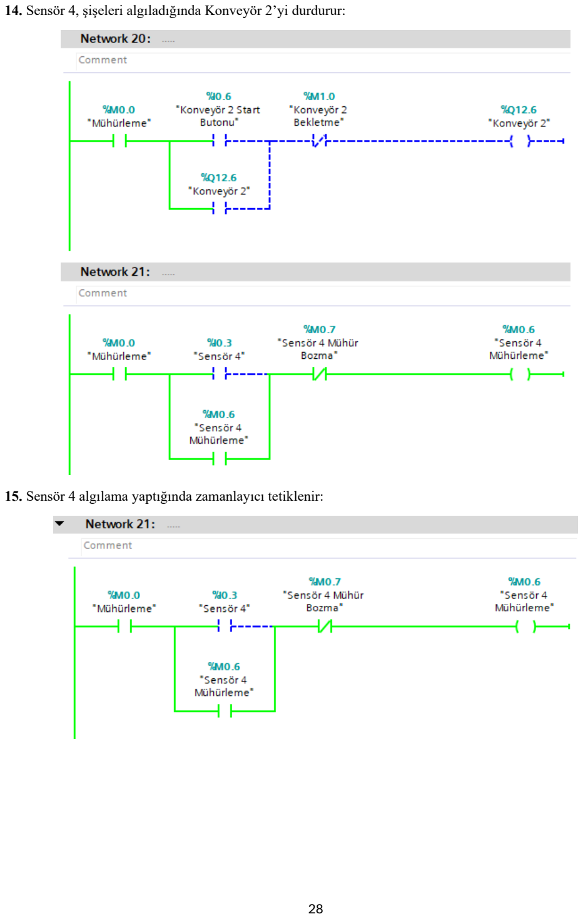
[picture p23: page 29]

### 14. Sensör 4, şişeleri algıladığında Konveyör 2’yi durdurur:

### 15. Sensör 4 algılama yaptığında zamanlayıcı tetiklenir:

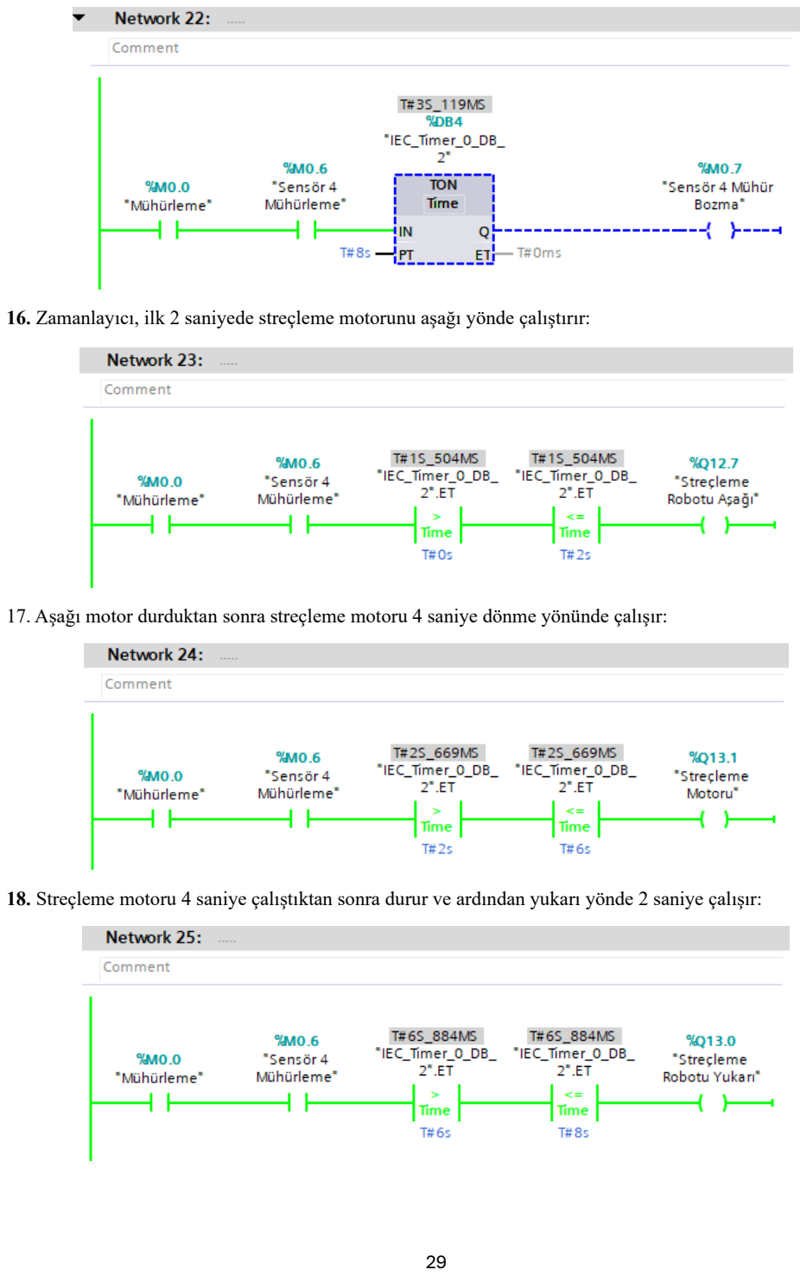
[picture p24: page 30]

### 16. Zamanlayıcı, ilk 2 saniyede streçleme motorunu aşağı yönde çalıştırır:

17. Aşağı motor durduktan sonra streçleme motoru 4 saniye dönme yönünde çalışır:
18. Streçleme motoru 4 saniye çalıştıktan sonra durur ve ardından yukarı yönde 2 saniye çalışır:

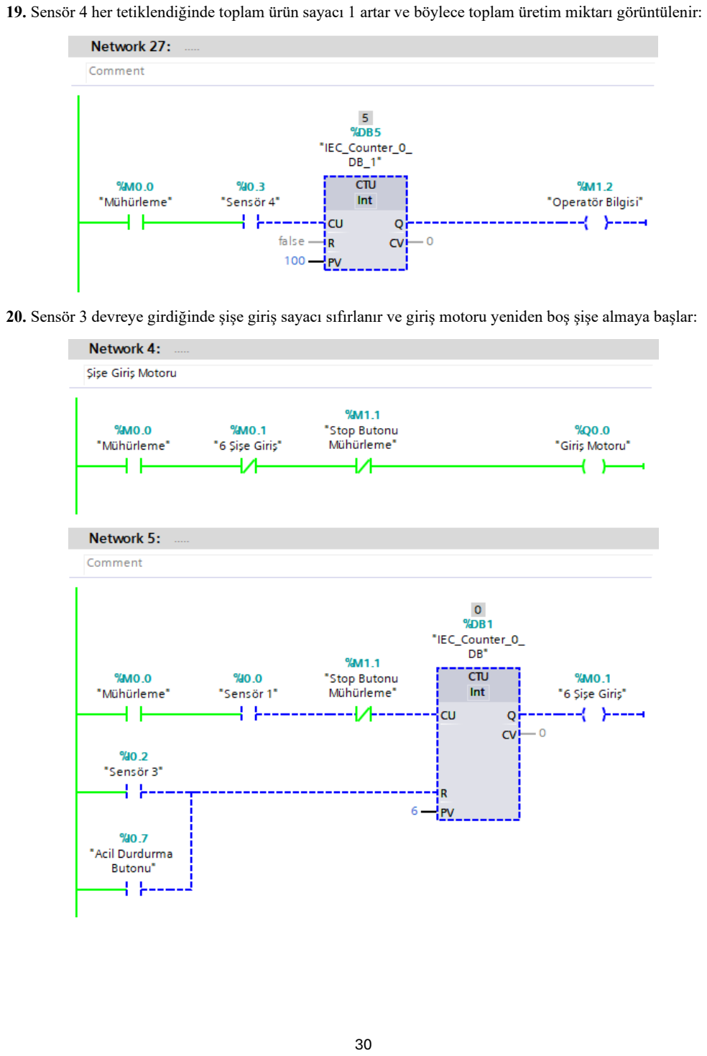
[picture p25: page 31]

19. Sensör 4 her tetiklendiğinde toplam ürün sayacı 1 artar ve böylece toplam üretim miktarı görüntülenir:
20. Sensör 3 devreye girdiğinde şişe giriş sayacı sıfırlanır ve giriş motoru yeniden boş şişe almaya başlar:

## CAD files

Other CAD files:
Wiring-Diagrams.dwg

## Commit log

2025-12-05 Revise README for project details and structure
    Updated the README to provide a comprehensive overview of the industrial bottle filling and packaging automation project, including sections on system architecture, hardware components, process flow,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
2025-12-09 Fix link case for project report download
2025-12-09 Fix link case sensitivity in project report download
